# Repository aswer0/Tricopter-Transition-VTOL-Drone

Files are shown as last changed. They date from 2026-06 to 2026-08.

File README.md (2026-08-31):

# Tricopter-Transition-VTOL-Drone

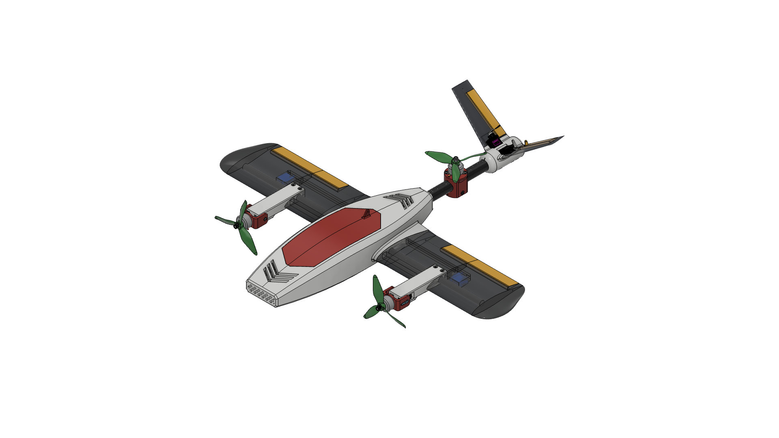
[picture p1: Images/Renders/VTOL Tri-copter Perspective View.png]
Perspective View

This VTOL (Vertical Take-off and Landing) Tricopter UAV (Unmanned Aerial Vehicle) is fully 3D printed and reinforced with carbon fiber rods. It can transition from vertical flight as a standard tricopter to forward flight as a fixed wing UAV by tilting its front 2 propellers.

Demo Link: https://youtube.com/shorts/rxa7jozEfoo?feature=share

***

## Motivation
I was inspired to start this project after seeing the growing usage of standard drones in everyday life. I wanted to combine the efficiency of a fixed wing UAV with the unique ability of a tricopter/quadcopter to hover, which is how I decided on this transition VTOL design.

***

## Specifications
- Length: 650 mm
- Wingspan: 700 mm
- Weight (w/ battery): 870 g
- Max Thrust: 3072 g
- Airfoil: HQ 3.0/14

***

## Bill of Materials (BOM)

| Item | Qty | Cost (USD) | Purchase Link |
| --- | --- | --- | --- |
| 20 × 22 × 330 mm Carbon Fiber Rod | 1 | $12.89 | [Amazon](https://a.co/d/0fRC7tl8) |
| 10 × 12 × 600 mm Carbon Fiber Rod (2 pc) | 1 | $16.99 | [Amazon](https://a.co/d/0hknHJLD) |
| KM1203MD Servo (2 pc pack) | 2 | $56.50 | [Amazon](https://a.co/d/04CT49QQ) |
| 3 mm Bushing | 2 | $6.97 | [Amazon](https://a.co/d/00eb9Lxp) |
| 5 in. Propeller (4 pc pack) | 3 | $9.59 | [Amazon](https://a.co/d/0hknHJLD) |
| RS2205 2300 kV Motor (4 pc pack) | 3 | $36.99 | [Amazon](https://a.co/d/0gNAh0BJ) |
| FS-iA6B Receiver | 1 | $17.99 | [Amazon](https://a.co/d/01dz03wv) |
| AERO SELFIE 4-in-1 45A ESC | 1 | $32.90 | [Amazon](https://a.co/d/0g2pQsMn) |
| MG90S Servo | 4 | $13.88 | [Amazon](https://a.co/d/0epTO13h) |
| Teensy 4.0 | 1 | $24.60 | [Amazon](https://a.co/d/04LAZwGB) |
| MPU6050 9-axis IMU | 1 | $6.99 | [Amazon](https://a.co/d/0g5Ldqw0) |
| Ovonic 4S 1300 mAh LiPo Battery | 1 | $18.99 | [Amazon](https://a.co/d/0c603tkp) |
| 1kg LW-PLA | 1 | $24.99 | [Amazon](https://a.co/d/0acjByZF) |
| 1kg PLA | 1 | $11.99 | [Amazon](https://a.co/d/025aT8S4) |
| M3×6 Button Head Screw | 8 | $9.99 | [Amazon](https://a.co/d/0h7R8a6U) |
| M3×8 Button Head Screw | 6 | | Included in M3 hardware kit |
| M3×14 Button Head Screw | 2 | | Included in M3 hardware kit |
| M3 Nut | 2 | | Included in M3 hardware kit |
| M4×16 Socket Head Screw | 4 | $8.99 | [Amazon](https://a.co/d/0cEMfsPs) |
| M4×30 Button Head Screw | 1 | | Included in M4 hardware kit |
| M4 Nut | 5 | | Included in M4 hardware kit |

Total Cost: $311.24

***

## Printing Instructions

- Every part can be printed on a 180x180x180mm print bed.
- For every wing (W) and aileron (A) part, you need to print one version as is, and one mirrored version.
- These following parts should be printed with vase mode using LW-PLA: W1, W2, W3, A1, A3, F1, C1, C2.
- The "Front Plate" part should be printed out of PLA with 0 top/bottom walls, 2 normal walls and 35% honeycomb infill.
- All other parts should be printed using normal PLA with 2 walls and 2-5% gyroid infill.

***

## Assembly Instructions

Nacelles:
1. Screw a CCW motor onto the front motor mount using 4x M3x6mm screws.
2. Screw the tilt servo (not MG90S) into the right nacelle using the provided self-threading screws.
3. Pressfit a 3mm bushing onto the motor mount.
4. Attach the motor mount to the nacelle by pressfitting a servo horn into the indent, and using a M3x8mm screw to connect the bushing side.
5. Run the wires through the tunnel and out the side.
6. Repeat steps 1-5 for the left side (using a CW motor).

Wing:
1. Glue each wing piece in order using CA glue (W1, W2, W3).
2. Glue each aileron piece together.
3. Run a piece of PLA filament through the aileron hole and use that to attach it to the wing.
4. Use hot glue to attach the MG90S servo.

Fuselage and Canopy:
1. Glue each piece in order using CA glue (F1 in the front, F3 in the back.
2. Glue together the canopy pieces (C1, C2, C3).
3. Using CA glue, attach the front latch piece to the front of C1.
4. Glue the Spring Mount near the seam between C2 and C3.
5. Insert a ballpoint pen spring into the mount, then slide L1 and L2 into the slot in C3 before gluing it in place. The latch should move freely front and back.

Tail:
1. Glue the two tail pieces to the middle clamp.
2. Attach the ruddervators to the tail with a piece of PLA filament as the hinge.
3. Use hot glue to install each MG90S servo.

Assembly:
1. Insert the 600mm CF rod into the side of the fuselage.
2. Slide the wings and nacelles into place and secure with CA glue. Make sure to run the wires using the tunnels into the fuselage.
3. Hot glue the 330mm CF rod into the back of the fuselage.
4. Screw on the back motor to its mount, then clamp the mount onto the CF rod.
5. Slide the tail assembly into place and clamp it using M3 screws. Run the servo wires (with extensions) through the CF tube to the fuselage.

Electronics:
1. Glue the 3 electronics mounts (ESC, Teensy, IMU) into the fuselage.
2. Screw in the ESC using the included M3 screws and rubber grommets.
3. Use VHB to attach the Teensy to its mount, the IMU to its mount, and the receiver to the side of the fuselage.
4. Attach a piece of velcro for the battery somewhere inside F1 so that the position of the battery can be shifted to adjust the center of gravity.
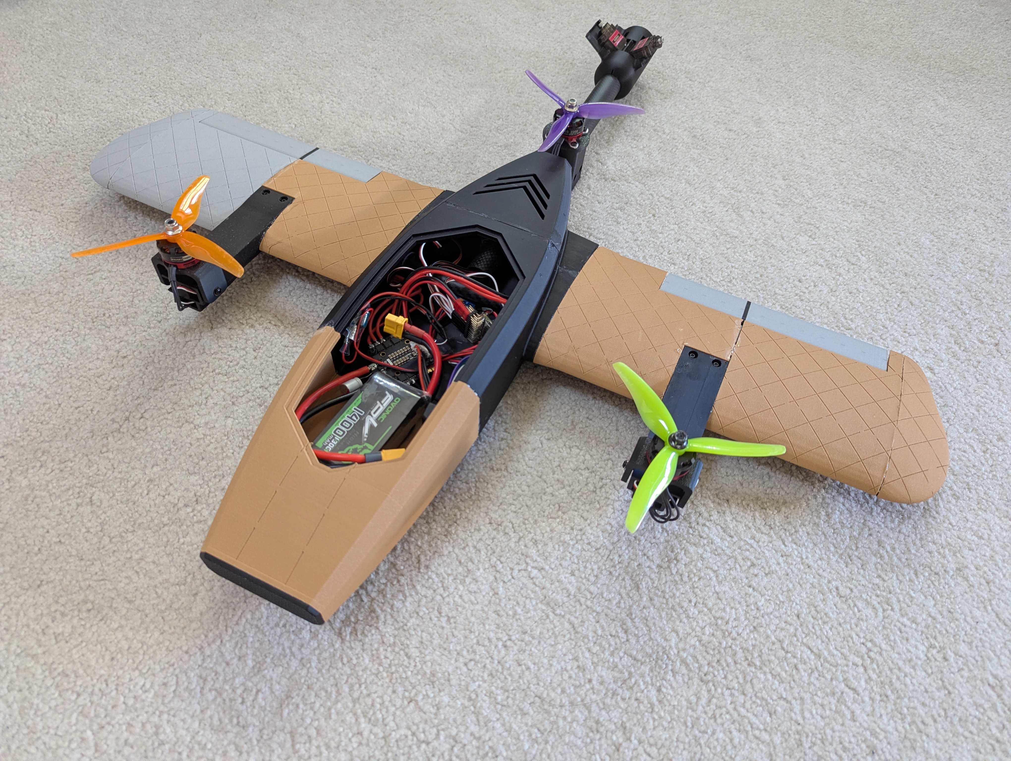
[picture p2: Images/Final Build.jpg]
Build in Progress

***

## Electronics

The electronics are based around the open-sourced flight controller Drehmflight, which uses a Teensy 4.0 board. There are no PCBs involved and all the components are soldered and wired together.

The schematics are shown below, and can also be viewed in KiCAD.


***

## Software

The flight controller runs a modified version of Drehmflight, made by Nicholas Rehm. The full documentation for Drehmflight can be found here: https://github.com/nickrehm/dRehmFlight/blob/master/dRehmFlight%20VTOL%20Documentation.pdf

To compile the firmware, download the source code under the "Firmware" tab, open it in Arduino IDE, then upload to the Teensy 4.0 board over USB.

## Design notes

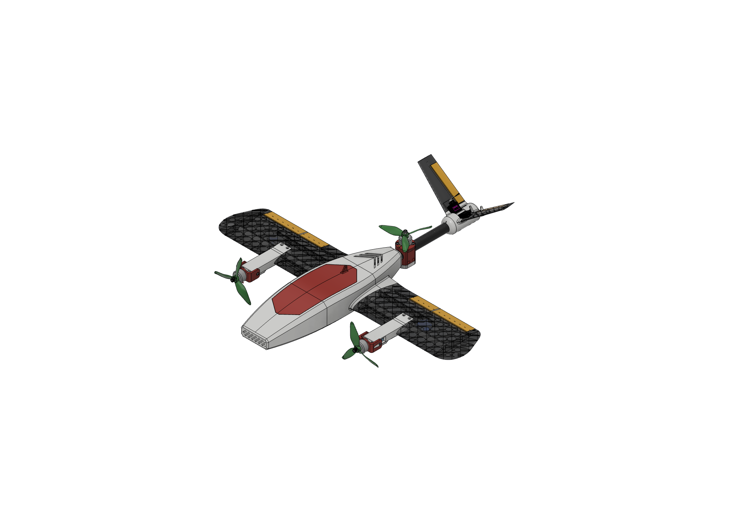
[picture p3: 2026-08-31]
Images/Renders/VTOL Tri-copter v19.png

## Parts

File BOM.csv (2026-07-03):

Item | Qty | Cost (USD) | Purchase Link
20 × 22 × 330 mm Carbon Fiber Rod | 1 | 12.89 | https://a.co/d/0fRC7tl8
10 × 12 × 600 mm Carbon Fiber Rod (2 pc) | 1 | 16.99 | https://a.co/d/0cOCjby6
KM1203MD Servo (2 pc pack) | 2 | 56.50 | https://a.co/d/04CT49QQ
3 mm Bushing | 2 | 6.97 | https://a.co/d/00eb9Lxp
5 in. Propeller (4 pc pack) | 3 | 9.59 | https://a.co/d/07Ut5IjC
RS2205 2300 kV Motor (4 pc pack) | 3 | 36.99 | https://a.co/d/0gNAh0BJ
FS-iA6B Receiver | 1 | 17.99 | https://a.co/d/01dz03wv
AERO SELFIE 4-in-1 45A ESC | 1 | 32.90 | https://a.co/d/0g2pQsMn
MG90S Servo | 4 | 13.88 | https://a.co/d/0epTO13h
Teensy 4.0 | 1 | 24.60 | https://a.co/d/04LAZwGB
MPU6050 9-axis IMU | 1 | 6.99 | https://a.co/d/0g5Ldqw0
Ovonic 4S 1300 mAh LiPo Battery | 1 | 18.99 | https://a.co/d/0c603tkp
1 kg LW-PLA | 1 | 24.99 | https://a.co/d/0acjByZF
1 kg PLA | 1 | 11.99 | https://a.co/d/025aT8S4
M3×6 Button Head Screw | 8 | 9.99 | https://a.co/d/0h7R8a6U
M3×8 Button Head Screw | 6
M3×14 Button Head Screw | 2
M3 Nut | 2
M4×16 Socket Head Screw | 4 | 8.99 | https://a.co/d/0cEMfsPs
M4×30 Button Head Screw | 1
M4 Nut | 5

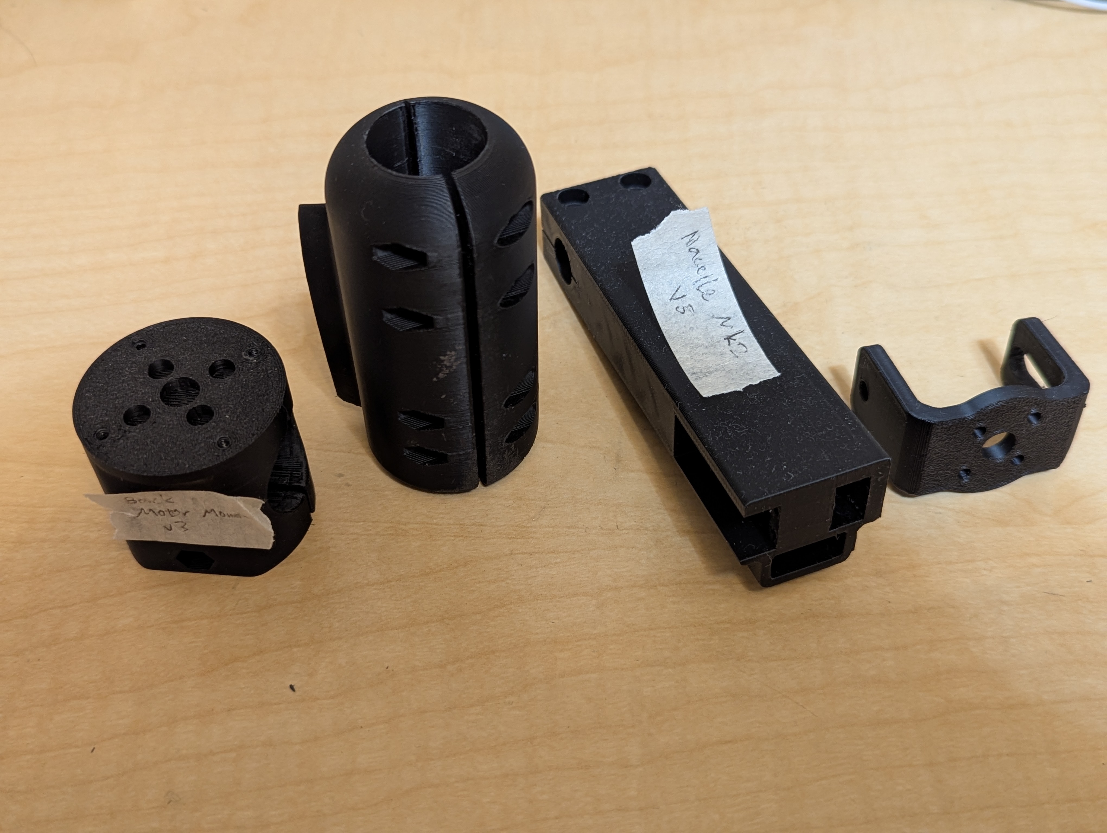
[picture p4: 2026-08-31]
Images/Build/Misc Parts.jpg

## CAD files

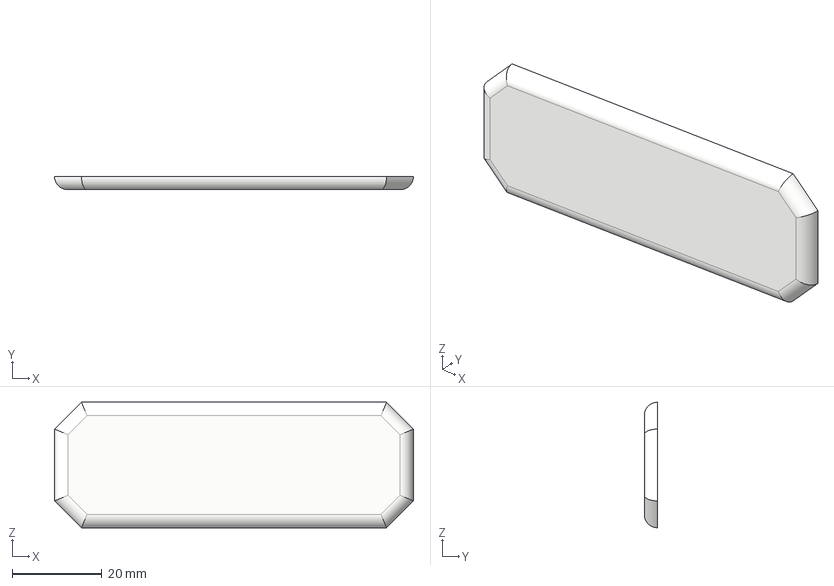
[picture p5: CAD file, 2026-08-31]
CAD/STEP/Fuselage/Front plate.step
80.0 x 3.00 x 28.0 mm

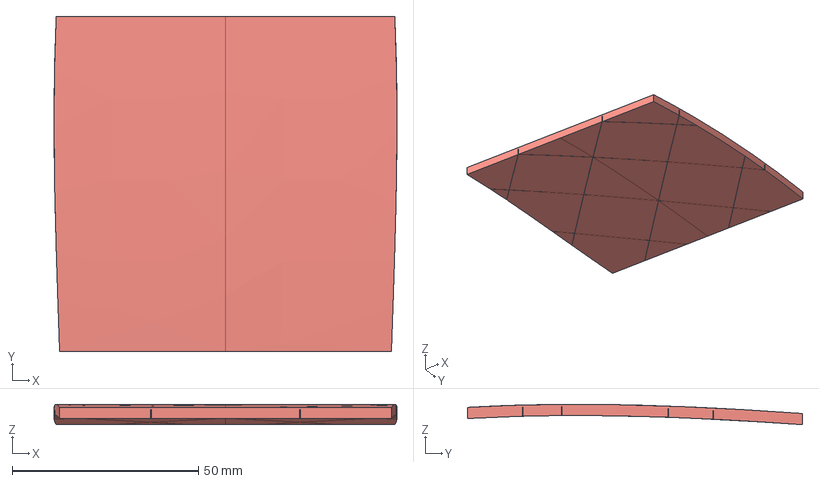
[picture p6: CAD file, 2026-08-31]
CAD/STEP/Miscellaneous/C2.step
92.0 x 90.0 x 5.46 mm

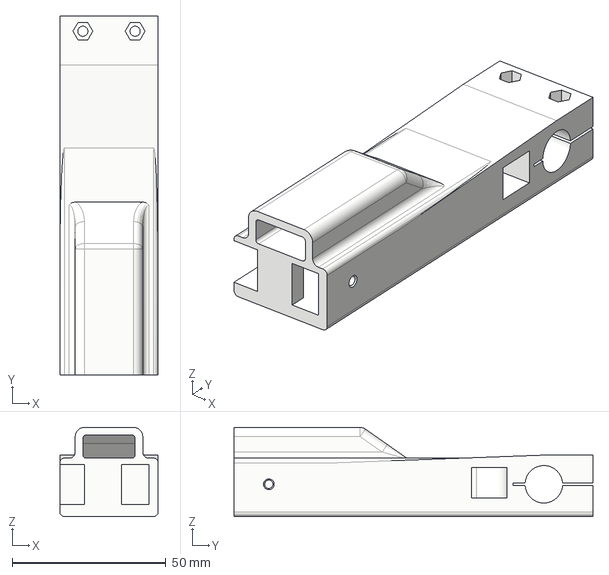
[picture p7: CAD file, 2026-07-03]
CAD/STEP/Nacelles/Nacelle Left.step
32.0 x 116.8 x 29.0 mm

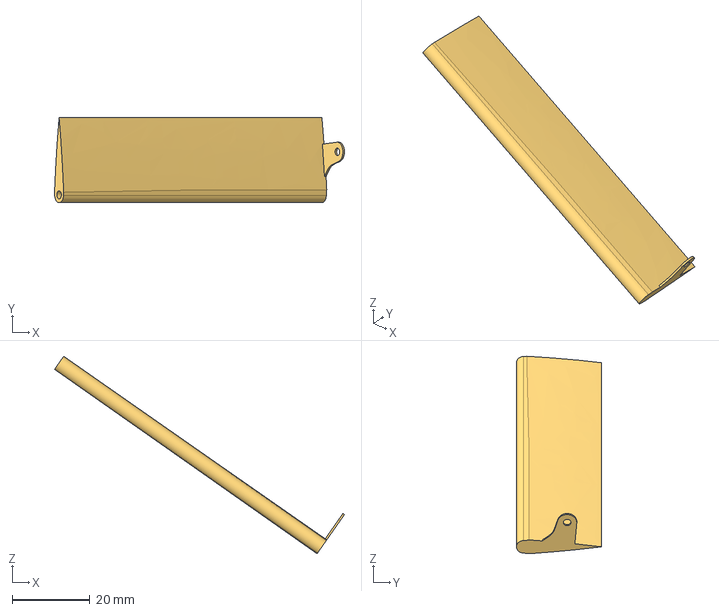
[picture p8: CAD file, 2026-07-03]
CAD/STEP/Tail/Ruddervator2 Right.step
74.8 x 22.0 x 51.0 mm

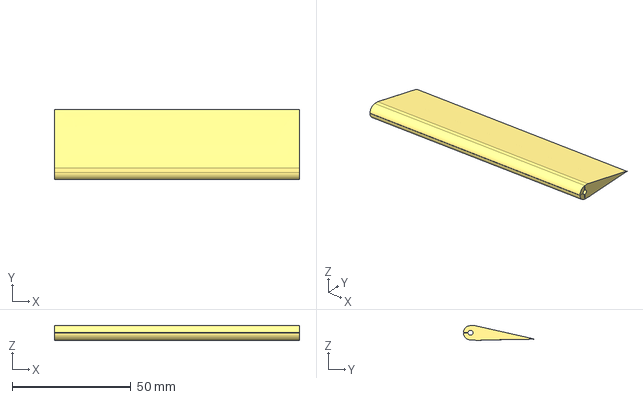
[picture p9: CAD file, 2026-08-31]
CAD/STEP/Wing/A3.step
103.1 x 29.5 x 6.20 mm

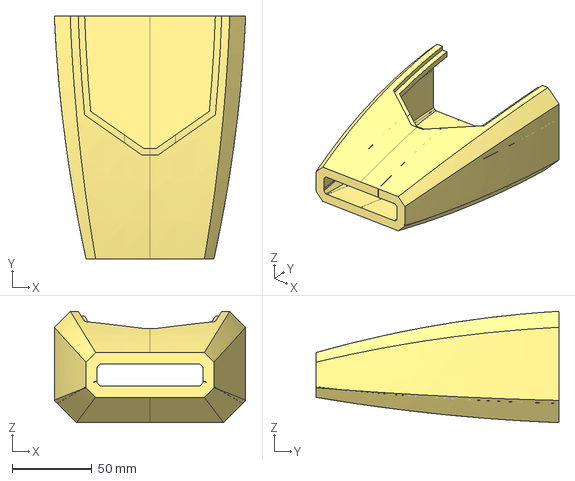
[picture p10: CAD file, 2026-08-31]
CAD/STEP/Fuselage/F1.step
119.7 x 152.0 x 69.7 mm

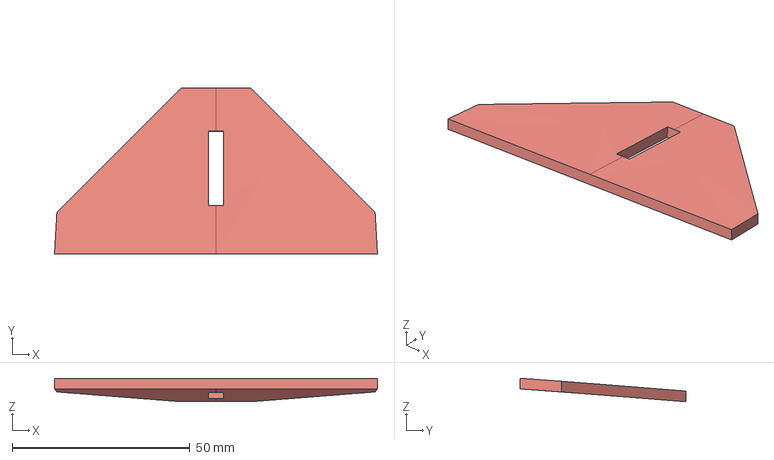
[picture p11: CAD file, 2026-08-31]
CAD/STEP/Miscellaneous/C3.step
90.9 x 46.6 x 6.61 mm

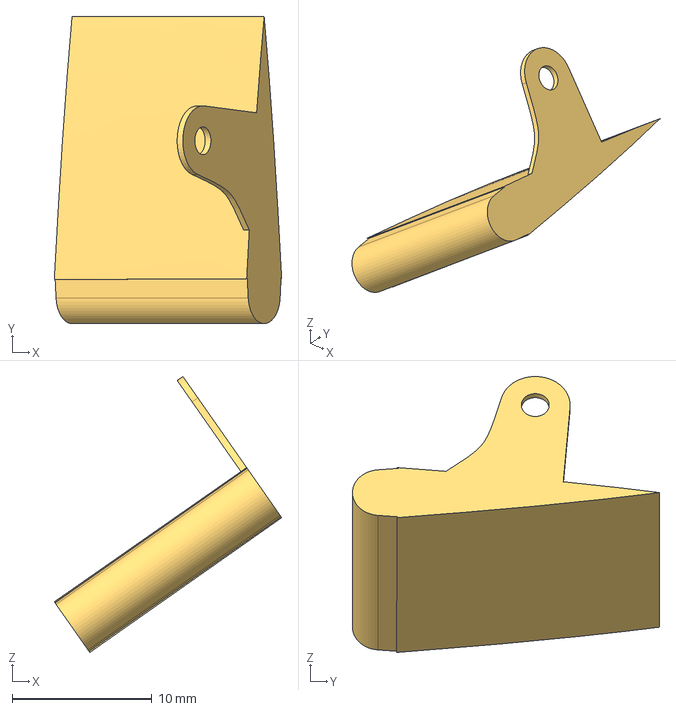
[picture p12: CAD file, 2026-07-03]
CAD/STEP/Tail/Ruddervator1 Left.step
16.3 x 22.0 x 19.8 mm

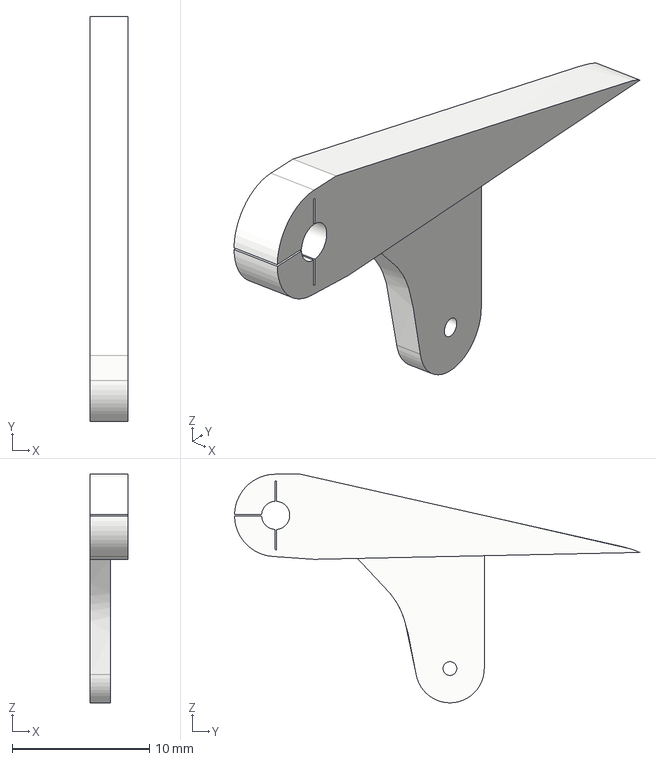
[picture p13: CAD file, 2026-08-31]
CAD/STEP/Wing/A2.step
2.75 x 29.5 x 16.7 mm

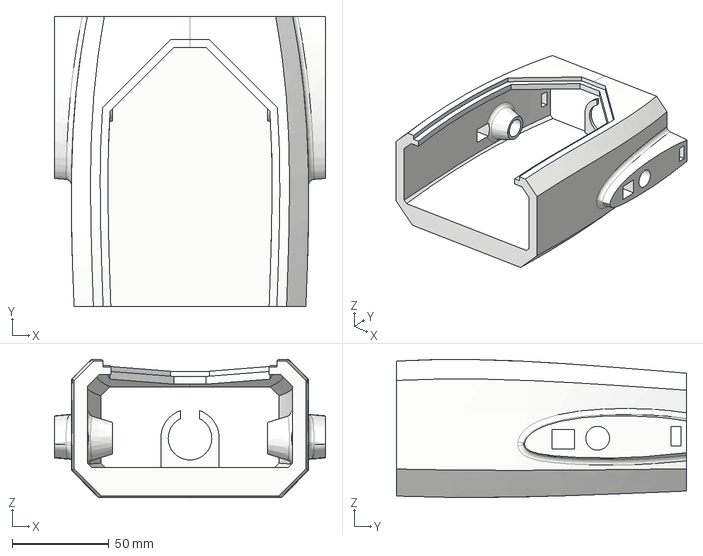
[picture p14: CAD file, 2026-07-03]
CAD/STEP/Fuselage/F2.step
140.0 x 150.0 x 71.3 mm

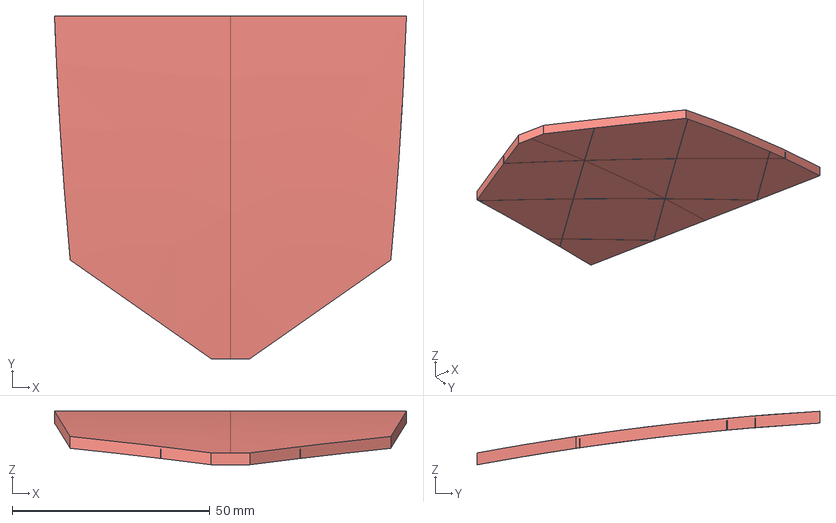
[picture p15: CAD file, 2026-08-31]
CAD/STEP/Miscellaneous/C1.step
89.0 x 86.6 x 13.5 mm

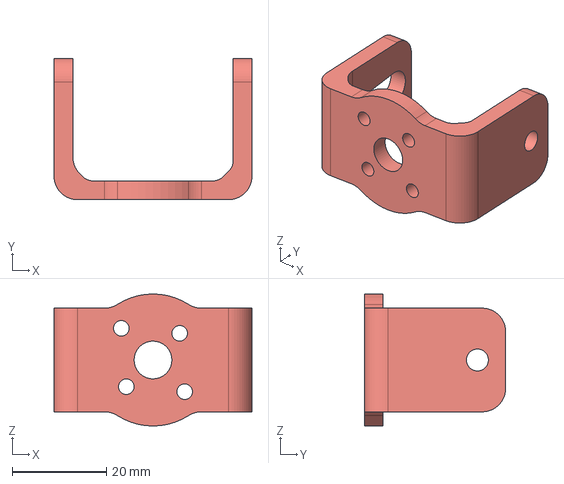
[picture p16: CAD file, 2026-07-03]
CAD/STEP/Nacelles/Front Motor Mount.step
42.0 x 30.0 x 28.0 mm

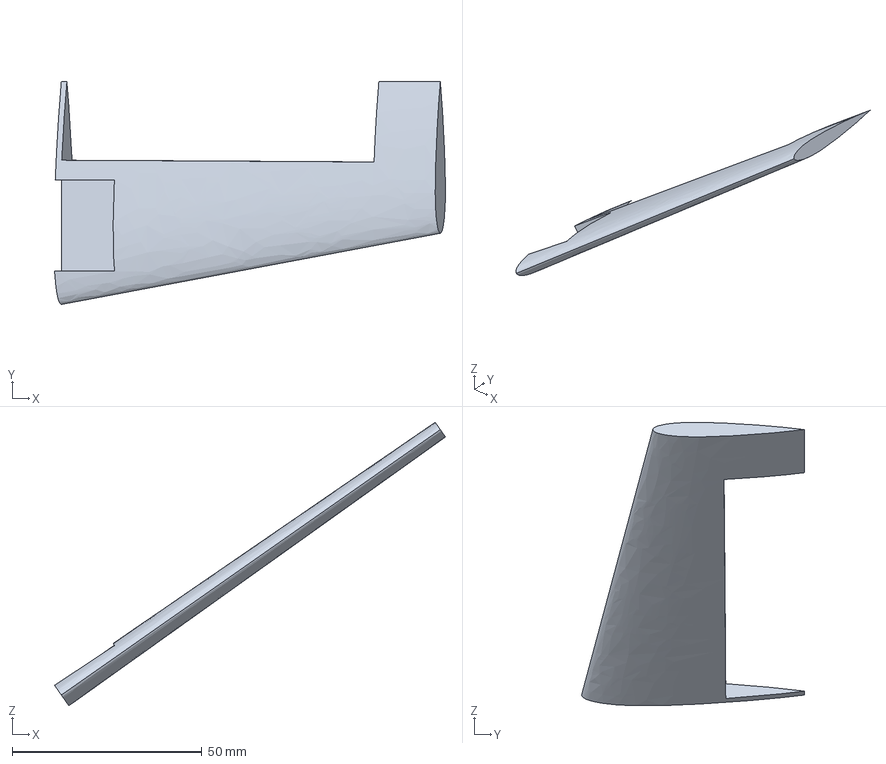
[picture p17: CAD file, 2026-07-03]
CAD/STEP/Tail/Left Tail.step
103.1 x 58.8 x 74.7 mm

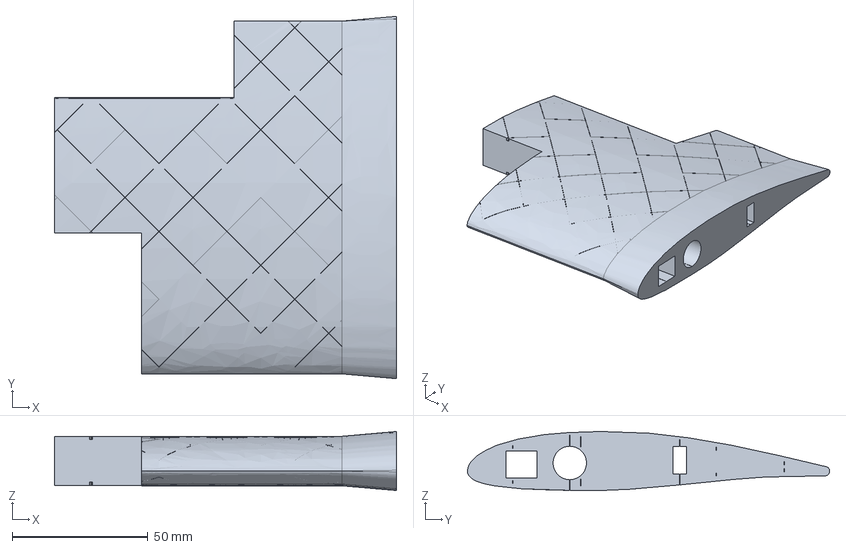
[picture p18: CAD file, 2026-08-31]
CAD/STEP/Wing/W1.step
126.0 x 133.5 x 21.7 mm

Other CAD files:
CAD/STEP/Nacelles/Nacelle Right.step
CAD/STEP/Fuselage/F3.step
CAD/STEP/Miscellaneous/L1.step
CAD/STEP/Tail/Ruddervator1 Right.step
CAD/STEP/Miscellaneous/Back Motor Mount.step
CAD/STEP/Miscellaneous/ESC Mount.step
CAD/STEP/Miscellaneous/Front Latch.step
CAD/STEP/Miscellaneous/IMU Mount.step
CAD/STEP/Miscellaneous/L2.step
CAD/STEP/Miscellaneous/Spring Mount.step
CAD/STEP/Miscellaneous/Teensy_Block Mount.step
CAD/STEP/Tail/Right Tail.step
CAD/STEP/Tail/Ruddervator2 Left.step
CAD/STEP/Tail/Tail Clamp.step
CAD/STEP/Wing/A1.step
CAD/STEP/Wing/W2.step
CAD/STEP/Wing/W3.step
CAD/STL/Fuselage/F1.stl
CAD/STL/Fuselage/F2.stl
CAD/STL/Fuselage/F3.stl
CAD/STL/Fuselage/Front plate.stl
CAD/STL/Miscellaneous/Back Motor Mount.stl
CAD/STL/Miscellaneous/C1.stl
CAD/STL/Miscellaneous/C2.stl
CAD/STL/Miscellaneous/C3.stl
CAD/STL/Miscellaneous/ESC Mount.stl
CAD/STL/Miscellaneous/Front Latch.stl
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

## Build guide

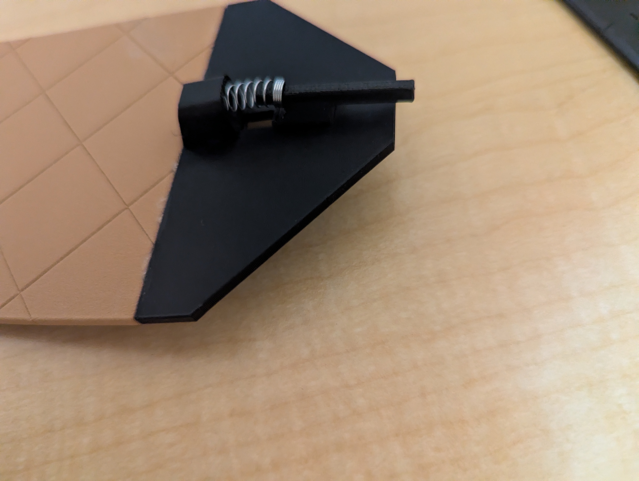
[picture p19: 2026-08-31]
Images/Build/Latch.jpg

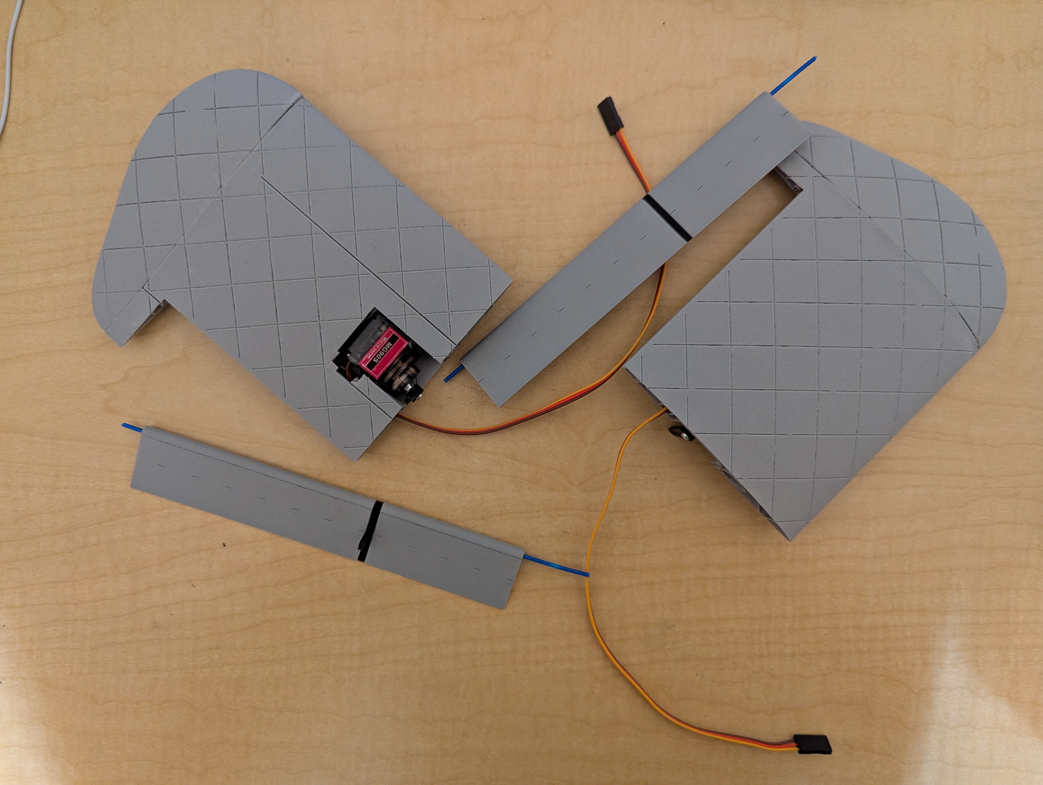
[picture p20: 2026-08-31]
Images/Build/Wings.jpg

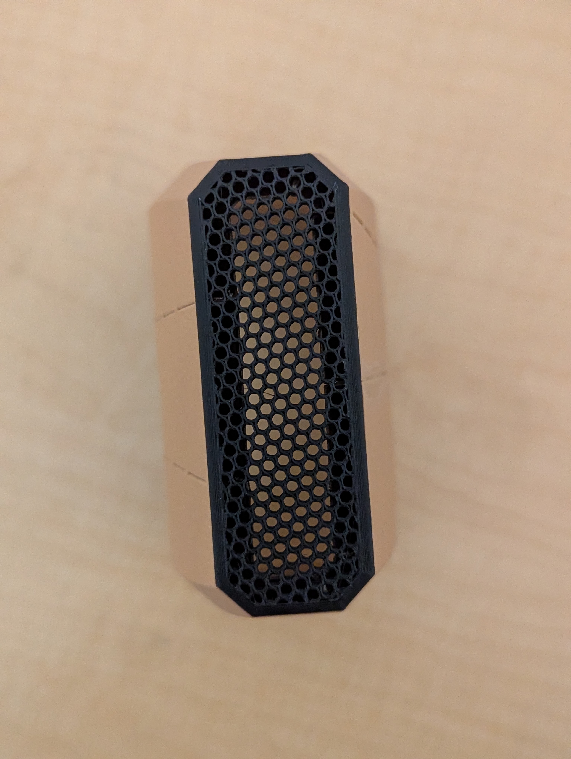
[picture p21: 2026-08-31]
Images/Build/Front plate.jpg

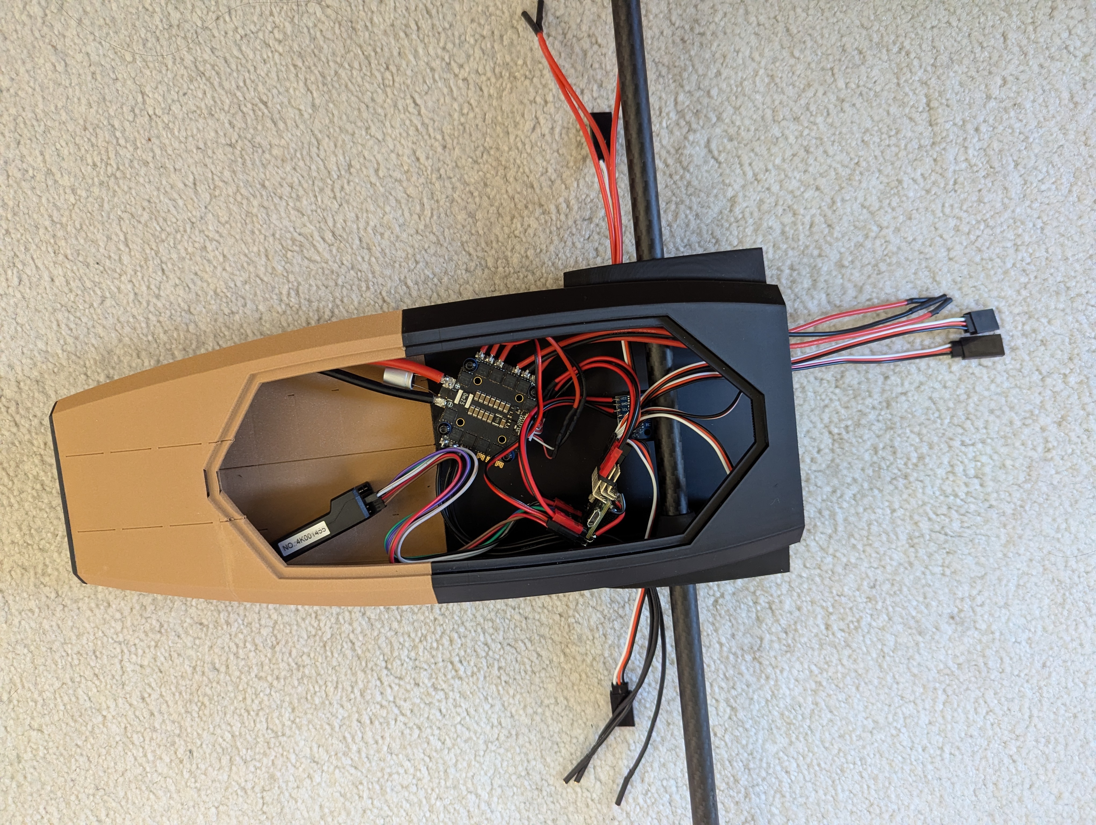
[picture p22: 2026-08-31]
Images/Build/Fuselage Build 1.jpg

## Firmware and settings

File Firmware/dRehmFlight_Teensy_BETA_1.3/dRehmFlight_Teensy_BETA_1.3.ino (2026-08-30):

//Arduino/Teensy Flight Controller - dRehmFlight
//Author: Nicholas Rehm
//Project Start: 1/6/2020
//Last Updated: 7/29/2022
//Version: Beta 1.3
 
//========================================================================================================================//

//CREDITS + SPECIAL THANKS
/*
Some elements inspired by:
http://www.brokking.net/ymfc-32_main.html

Madgwick filter function adapted from:
https://github.com/arduino-libraries/MadgwickAHRS

MPU9250 implementation based on MPU9250 library by:
brian.taylor@bolderflight.com
http://www.bolderflight.com

Thank you to:
RcGroups 'jihlein' - IMU implementation overhaul + SBUS implementation.
Everyone that sends me pictures and videos of your flying creations! -Nick

*/



//========================================================================================================================//
//                                                 USER-SPECIFIED DEFINES                                                 //                                                                 
//========================================================================================================================//

//Uncomment only one receiver type
#define USE_PWM_RX
//#define USE_PPM_RX
//#define USE_SBUS_RX
//#define USE_DSM_RX
static const uint8_t num_DSM_channels = 6; //If using DSM RX, change this to match the number of transmitter channels you have

//Uncomment only one IMU
#define USE_MPU6050_I2C //Default
//#define USE_MPU9250_SPI

//Uncomment only one full scale gyro range (deg/sec)
#define GYRO_250DPS //Default
//#define GYRO_500DPS
//#define GYRO_1000DPS
//#define GYRO_2000DPS

//Uncomment only one full scale accelerometer range (G's)
#define ACCEL_2G //Default
//#define ACCEL_4G
//#define ACCEL_8G
//#define ACCEL_16G



//========================================================================================================================//



//REQUIRED LIBRARIES (included with download in main sketch folder)

#include <Wire.h>     //I2c communication
#include <SPI.h>      //SPI communication
#include <PWMServo.h> //Commanding any extra actuators, installed with teensyduino installer

#if defined USE_SBUS_RX
  #include "src/SBUS/SBUS.h"   //sBus interface
#endif

#if defined USE_DSM_RX
  #include "src/DSMRX/DSMRX.h"  
#endif

#if defined USE_MPU6050_I2C
  #include "src/MPU6050/MPU6050.h"
  MPU6050 mpu6050;
#elif defined USE_MPU9250_SPI
  #include "src/MPU9250/MPU9250.h"
  MPU9250 mpu9250(SPI2,36);
#else
  #error No MPU defined... 
#endif



//========================================================================================================================//



//Setup gyro and accel full scale value selection and scale factor

#if defined USE_MPU6050_I2C
  #define GYRO_FS_SEL_250    MPU6050_GYRO_FS_250
  #define GYRO_FS_SEL_500    MPU6050_GYRO_FS_500
  #define GYRO_FS_SEL_1000   MPU6050_GYRO_FS_1000
  #define GYRO_FS_SEL_2000   MPU6050_GYRO_FS_2000
  #define ACCEL_FS_SEL_2     MPU6050_ACCEL_FS_2
  #define ACCEL_FS_SEL_4     MPU6050_ACCEL_FS_4
  #define ACCEL_FS_SEL_8     MPU6050_ACCEL_FS_8
  #define ACCEL_FS_SEL_16    MPU6050_ACCEL_FS_16
#elif defined USE_MPU9250_SPI
  #define GYRO_FS_SEL_250    mpu9250.GYRO_RANGE_250DPS
  #define GYRO_FS_SEL_500    mpu9250.GYRO_RANGE_500DPS
  #define GYRO_FS_SEL_1000   mpu9250.GYRO_RANGE_1000DPS                                                        
  #define GYRO_FS_SEL_2000   mpu9250.GYRO_RANGE_2000DPS
  #define ACCEL_FS_SEL_2     mpu9250.ACCEL_RANGE_2G
  #define ACCEL_FS_SEL_4     mpu9250.ACCEL_RANGE_4G
  #define ACCEL_FS_SEL_8     mpu9250.ACCEL_RANGE_8G
  #define ACCEL_FS_SEL_16    mpu9250.ACCEL_RANGE_16G
#endif
  
#if defined GYRO_250DPS
  #define GYRO_SCALE GYRO_FS_SEL_250
  #define GYRO_SCALE_FACTOR 131.0
#elif defined GYRO_500DPS
  #define GYRO_SCALE GYRO_FS_SEL_500
  #define GYRO_SCALE_FACTOR 65.5
#elif defined GYRO_1000DPS
  #define GYRO_SCALE GYRO_FS_SEL_1000
  #define GYRO_SCALE_FACTOR 32.8
#elif defined GYRO_2000DPS
  #define GYRO_SCALE GYRO_FS_SEL_2000
  #define GYRO_SCALE_FACTOR 16.4
#endif

#if defined ACCEL_2G
  #define ACCEL_SCALE ACCEL_FS_SEL_2
  #define ACCEL_SCALE_FACTOR 16384.0
#elif defined ACCEL_4G
  #define ACCEL_SCALE ACCEL_FS_SEL_4
  #define ACCEL_SCALE_FACTOR 8192.0
#elif defined ACCEL_8G
  #define ACCEL_SCALE ACCEL_FS_SEL_8
  #define ACCEL_SCALE_FACTOR 4096.0
#elif defined ACCEL_16G
  #define ACCEL_SCALE ACCEL_FS_SEL_16
  #define ACCEL_SCALE_FACTOR 2048.0
#endif



//========================================================================================================================//
//                                               USER-SPECIFIED VARIABLES                                                 //                           
//========================================================================================================================//

//Radio failsafe values for every channel in the event that bad reciever data is detected. Recommended defaults:
unsigned long channel_1_fs = 1000; //thro
unsigned long channel_2_fs = 1500; //ail
unsigned long channel_3_fs = 1500; //elev
unsigned long channel_4_fs = 1500; //rudd
unsigned long channel_5_fs = 2000; //gear, greater than 1500 = throttle cut
unsigned long channel_6_fs = 2000; //aux1

//Filter parameters - Defaults tuned for 2kHz loop rate; Do not touch unless you know what you are doing:
float B_madgwick = 0.04;  //Madgwick filter parameter
float B_accel = 0.14;     //Accelerometer LP filter paramter, (MPU6050 default: 0.14. MPU9250 default: 0.2)
float B_gyro = 0.1;       //Gyro LP filter paramter, (MPU6050 default: 0.1. MPU9250 default: 0.17)
float B_mag = 1.0;        //Magnetometer LP filter parameter

//Magnetometer calibration parameters - if using MPU9250, uncomment calibrateMagnetometer() in void setup() to get these values, else just ignore these
float MagErrorX = 0.0;
float MagErrorY = 0.0; 
float MagErrorZ = 0.0;
float MagScaleX = 1.0;
float MagScaleY = 1.0;
float MagScaleZ = 1.0;

//IMU calibration parameters - calibrate IMU using calculate_IMU_error() in the void setup() to get these values, then comment out calculate_IMU_error()
float AccErrorX = 0.10;
float AccErrorY = 0.02;
float AccErrorZ = -0.08;
float GyroErrorX = -1.26;
float GyroErrorY = -3.09;
float GyroErrorZ = -0.99;

//Controller parameters (take note of defaults before modifying!): 
float i_limit = 25.0;     //Integrator saturation level, mostly for safety (default 25.0)
float maxRoll = 30.0;     //Max roll angle in degrees for angle mode (maximum ~70 degrees), deg/sec for rate mode 
float maxPitch = 30.0;    //Max pitch angle in degrees for angle mode (maximum ~70 degrees), deg/sec for rate mode
float maxYaw = 160.0;     //Max yaw rate in deg/sec

float Kp_roll_angle = 0.1;    //Roll P-gain - angle mode //0.2
float Ki_roll_angle = 0.1;    //Roll I-gain - angle mode 0.3
float Kd_roll_angle = 0.05;   //Roll D-gain - angle mode (has no effect on controlANGLE2)
float B_loop_roll = 0.9;      //Roll damping term for controlANGLE2(), lower is more damping (must be between 0 to 1)
float Kp_pitch_angle = 0.1;   //Pitch P-gain - angle mode //0.2
float Ki_pitch_angle = 0.1;   //Pitch I-gain - angle mode 0.3
float Kd_pitch_angle = 0.05;  //Pitch D-gain - angle mode (has no effect on controlANGLE2)
float B_loop_pitch = 0.9;     //Pitch damping term for controlANGLE2(), lower is more damping (must be between 0 to 1)

float Kp_roll_rate = 0.15;    //Roll P-gain - rate mode
float Ki_roll_rate = 0.2;     //Roll I-gain - rate mode
float Kd_roll_rate = 0.0002;  //Roll D-gain - rate mode (be careful when increasing too high, motors will begin to overheat!)
float Kp_pitch_rate = 0.15;   //Pitch P-gain - rate mode
float Ki_pitch_rate = 0.2;    //Pitch I-gain - rate mode
float Kd_pitch_rate = 0.0002; //Pitch D-gain - rate mode (be careful when increasing too high, motors will begin to overheat!)

float Kp_yaw = 0.35;           //Yaw P-gain
float Ki_yaw = 0.05;          //Yaw I-gain
float Kd_yaw = 0.00015;       //Yaw D-gain (be careful when increasing too high, motors will begin to overheat!)

//constants
const int SERVO1_MIN = 947; //LEFT SERVO
// const int SERVO1_VERTICAL_CENTER = 1050; //raw pwm
// const int SERVO1_HORIZONTAL_CENTER = 2000; //raw pwm
const float SERVO1_VERTICAL_CENTER = 0.12; //0.12
const float SERVO1_HORIZONTAL_CENTER = 0.88;
const int SERVO1_MAX = 2197;

const int SERVO2_MIN = 922; //RIGHT SERVO
// const int SERVO2_VERTICAL_CENTER = 2000; //raw pwm
// const int SERVO2_HORIZONTAL_CENTER = 1050; //raw pwm
const float SERVO2_VERTICAL_CENTER = 0.88; ///0.88
const float SERVO2_HORIZONTAL_CENTER = 0.12;
const int SERVO2_MAX = 2172;

// const float PITCH_TRIM = 0.0;
// const float ROLL_TRIM = 0.0;
// const float PITCH_OFFSET = 14.95; //3.7
// const float ROLL_OFFSET = -1.4; //1.0
const float TORQUE_SCALE = 1;//1.225
const float REAR_HOVER = 1.225; //1.225
const float k_pitch_servo = 1.0;


//========================================================================================================================//
//                                                     DECLARE PINS                                                       //                           
//========================================================================================================================//                                          

//NOTE: Pin 13 is reserved for onboard LED, pins 18 and 19 are reserved for the MPU6050 IMU for default setup
//Radio:
//Note: If using SBUS, connect to pin 21 (RX5), if using DSM, connect to pin 15 (RX3)

//SWAPPED channels around bc stick bind is different on my transmitter
int rawCh1Pin = 15; //throttle
int rawCh2Pin = 16; //ail
int rawCh3Pin = 17; //ele
int rawCh4Pin = 20; //rudd

const int ch1Pin = rawCh3Pin; //throttle
const int ch2Pin = rawCh1Pin; //ail
const int ch3Pin = rawCh2Pin; //ele
const int ch4Pin = rawCh4Pin; //rudd
const int ch5Pin = 21; //gear (throttle cut)
const int ch6Pin = 22; //aux1 (free aux channel)
const int PPM_Pin = 23;
//OneShot125 ESC pin outputs:
const int m1Pin = 0;
const int m2Pin = 1;
const int m3Pin = 2;
const int m4Pin = 3;
const int m5Pin = 4;
const int m6Pin = 5;
//PWM servo or ESC outputs:
const int servo1Pin = 6;
const int servo2Pin = 7;
const int servo3Pin = 8;
const int servo4Pin = 9;
const int servo5Pin = 10;
const int servo6Pin = 11;
const int servo7Pin = 12;
PWMServo servo1;  //Create servo objects to control a servo or ESC with PWM
PWMServo servo2;
PWMServo servo3;
PWMServo servo4;
PWMServo servo5;
PWMServo servo6;
PWMServo servo7;



//========================================================================================================================//



//DECLARE GLOBAL VARIABLES

//General stuff
float dt;
unsigned long current_time, prev_time;
unsigned long print_counter, serial_counter;
unsigned long blink_counter, blink_delay;
bool blinkAlternate;

//Radio communication:
unsigned long channel_1_pwm, channel_2_pwm, channel_3_pwm, channel_4_pwm, channel_5_pwm, channel_6_pwm;
unsigned long channel_1_pwm_prev, channel_2_pwm_prev, channel_3_pwm_prev, channel_4_pwm_prev;

#if defined USE_SBUS_RX
  SBUS sbus(Serial5);
  uint16_t sbusChannels[16];
  bool sbusFailSafe;
  bool sbusLostFrame;
#endif
#if defined USE_DSM_RX
  DSM1024 DSM;
#endif

//IMU:
float AccX, AccY, AccZ;
float AccX_prev, AccY_prev, AccZ_prev;
float GyroX, GyroY, GyroZ;
float GyroX_prev, GyroY_prev, GyroZ_prev;
float MagX, MagY, MagZ;
float MagX_prev, MagY_prev, MagZ_prev;
float roll_IMU, pitch_IMU, yaw_IMU;
float roll_IMU_prev, pitch_IMU_prev;
float q0 = 1.0f; //Initialize quaternion for madgwick filter
float q1 = 0.0f;
float q2 = 0.0f;
float q3 = 0.0f;

//Normalized desired state:
float thro_des, roll_des, pitch_des, yaw_des;
float roll_passthru, pitch_passthru, yaw_passthru;

//Controller:
float error_roll, error_roll_prev, roll_des_prev, integral_roll, integral_roll_il, integral_roll_ol, integral_roll_prev, integral_roll_prev_il, integral_roll_prev_ol, derivative_roll, roll_PID = 0;
float error_pitch, error_pitch_prev, pitch_des_prev, integral_pitch, integral_pitch_il, integral_pitch_ol, integral_pitch_prev, integral_pitch_prev_il, integral_pitch_prev_ol, derivative_pitch, pitch_PID = 0;
float error_yaw, error_yaw_prev, integral_yaw, integral_yaw_prev, derivative_yaw, yaw_PID = 0;

//Mixer
float m1_command_scaled, m2_command_scaled, m3_command_scaled, m4_command_scaled, m5_command_scaled, m6_command_scaled;
int m1_command_PWM, m2_command_PWM, m3_command_PWM, m4_command_PWM, m5_command_PWM, m6_command_PWM;
float s1_command_scaled, s2_command_scaled, s3_command_scaled, s4_command_scaled, s5_command_scaled, s6_command_scaled, s7_command_scaled;
int s1_command_PWM, s2_command_PWM, s3_command_PWM, s4_command_PWM, s5_command_PWM, s6_command_PWM, s7_command_PWM;

//Flight status
bool armedFly = false;

//========================================================================================================================//
//                                                      VOID SETUP                                                        //                           
//========================================================================================================================//
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
   *  Simulates the void loop(), but only for the purpose of providing throttle pass through to the motors, so that you can
   *  power up with throttle at full, let ESCs begin arming sequence, and lower throttle to zero. This function should only be
   *  uncommented when performing an ESC calibration.
   */
   while (true) {
      prev_time = current_time;      
      current_time = micros();      
      dt = (current_time - prev_time)/1000000.0;
    
      digitalWrite(13, HIGH); //LED on to indicate we are not in main loop

      getCommands(); //Pulls current available radio commands
      failSafe(); //Prevent failures in event of bad receiver connection, defaults to failsafe values assigned in setup
      getDesState(); //Convert raw commands to normalized values based on saturated control limits
      getIMUdata(); //Pulls raw gyro, accelerometer, and magnetometer data from IMU and LP filters to remove noise
      Madgwick(GyroX, -GyroY, -GyroZ, -AccX, AccY, AccZ, MagY, -MagX, MagZ, dt); //Updates roll_IMU, pitch_IMU, and yaw_IMU (degrees)
      getDesState(); //Convert raw commands to normalized values based on saturated control limits
      
      m1_command_scaled = thro_des;
      m2_command_scaled = thro_des;
      m3_command_scaled = thro_des;
      m4_command_scaled = thro_des;
      m5_command_scaled = thro_des;
      m6_command_scaled = thro_des;
      s1_command_scaled = thro_des;
      s2_command_scaled = thro_des;
      s3_command_scaled = thro_des;
      s4_command_scaled = thro_des;
      s5_command_scaled = thro_des;
      s6_command_scaled = thro_des;
      s7_command_scaled = thro_des;
      scaleCommands(); //Scales motor commands to 125 to 250 range (oneshot125 protocol) and servo PWM commands to 0 to 180 (for servo library)
    
      throttleCut(); //Directly sets motor commands to low based on state of ch5
      
      servo1.write(s1_command_PWM); 
      servo2.write(s2_command_PWM);
      servo3.write(s3_command_PWM);
      servo4.write(s4_command_PWM);
      servo5.write(s5_command_PWM);
      servo6.write(s6_command_PWM);
      servo7.write(s7_command_PWM);
      commandMotors(); //Sends command pulses to each motor pin using OneShot125 protocol
      
      //printRadioData(); //Radio pwm values (expected: 1000 to 2000)
      
      loopRate(2000); //Do not exceed 2000Hz, all filter parameters tuned to 2000Hz by default
   }
}

float floatFaderLinear(float param, float param_min, float param_max, float fadeTime, int state, int loopFreq){
  //DESCRIPTION: Linearly fades a float type variable between min and max bounds based on desired high or low state and time
  /*  
   *  Takes in a float variable, desired minimum and maximum bounds, fade time, high or low desired state, and the loop frequency 
   *  and linearly interpolates that param variable between the maximum and minimum bounds. This function can be called in controlMixer()
   *  and high/low states can be determined by monitoring the state of an auxillarly radio channel. For example, if channel_6_pwm is being 
   *  monitored to switch between two dynamic configurations (hover and forward flight), this function can be called within the logical 
   *  statements in order to fade controller gains, for example between the two dynamic configurations. The 'state' (1 or 0) can be used
   *  to designate the two final options for that control gain based on the dynamic configuration assignment to the auxillary radio channel.
   *  
   */
  float diffParam = (param_max - param_min)/(fadeTime*loopFreq); //Difference to add or subtract from param for each loop iteration for desired fadeTime

  if (state == 1) { //Maximum param bound desired, increase param by diffParam for each loop iteration
    param = param + diffParam;
  }
  else if (state == 0) { //Minimum param bound desired, decrease param by diffParam for each loop iteration
    param = param - diffParam;
  }

  param = constrain(param, param_min, param_max); //Constrain param within max bounds
  
  return param;
}

float floatFaderLinear2(float param, float param_des, float param_lower, float param_upper, float fadeTime_up, float fadeTime_down, int loopFreq){
  //DESCRIPTION: Linearly fades a float type variable from its current value to the desired value, up or down
  /*  
   *  Takes in a float variable to be modified, desired new position, upper value, lower value, fade time, and the loop frequency 
   *  and linearly fades that param variable up or down to the desired value. This function can be called in controlMixer()
   *  to fade up or down between flight modes monitored by an auxillary radio channel. For example, if channel_6_pwm is being 
   *  monitored to switch between two dynamic configurations (hover and forward flight), this function can be called within the logical 
   *  statements in order to fade controller gains, for example between the two dynamic configurations. 
   *  
   */
  if (param > param_des) { //Need to fade down to get to desired
    float diffParam = (param_upper - param_des)/(fadeTime_down*loopFreq);
    param = param - diffParam;
  }
  else if (param < param_des) { //Need to fade up to get to desired
    float diffParam = (param_des - param_lower)/(fadeTime_up*loopFreq);
    param = param + diffParam;
  }

  param = constrain(param, param_lower, param_upper); //Constrain param within max bounds
  
  return param;
}

void switchRollYaw(int reverseRoll, int reverseYaw) {
  //DESCRIPTION: Switches roll_des and yaw_des variables for tailsitter-type configurations
  /*
   * Takes in two integers (either 1 or -1) corresponding to the desired reversing of the roll axis and yaw axis, respectively.
   * Reversing of the roll or yaw axis may be needed when switching between the two for some dynamic configurations. Inputs of 1, 1 does not 
   * reverse either of them, while -1, 1 will reverse the output corresponding to the new roll axis. 
   * This function may be replaced in the future by a function that switches the IMU data instead (so that angle can also be estimated with the 
   * IMU tilted 90 degrees from default level).
   */
  float switch_holder;

  switch_holder = yaw_des;
  yaw_des = reverseYaw*roll_des;
  roll_des = reverseRoll*switch_holder;
}

void throttleCut() {
  //DESCRIPTION: Directly set actuator outputs to minimum value if triggered
  /*
      Monitors the state of radio command channel_5_pwm and directly sets the mx_command_PWM values to minimum (120 is
      minimum for oneshot125 protocol, 0 is minimum for standard PWM servo library used) if channel 5 is high. This is the last function
      called before commandMotors() is called so that the last thing checked is if the user is giving permission to command
      the motors to anything other than minimum value. Safety first.

      channel_5_pwm is LOW then throttle cut is OFF and throttle value can change. (ThrottleCut is DEACTIVATED)
      channel_5_pwm is HIGH then throttle cut is ON and throttle value = 120 only. (ThrottleCut is ACTIVATED), (drone is DISARMED)
  */
  if ((channel_5_pwm > 1500) || (armedFly == false)) {
    armedFly = false;
    m1_command_PWM = 120;
    m2_command_PWM = 120;
    m3_command_PWM = 120;
    m4_command_PWM = 120;
    m5_command_PWM = 120;
    m6_command_PWM = 120;

    //Uncomment if using servo PWM variables to control motor ESCs
    //s1_command_PWM = 0;
    //s2_command_PWM = 0;
    //s3_command_PWM = 0;
    //s4_command_PWM = 0;
    //s5_command_PWM = 0;
    //s6_command_PWM = 0;
    //s7_command_PWM = 0;
  }
}
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

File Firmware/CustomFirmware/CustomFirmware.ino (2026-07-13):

#include <Servo.h>

int m1_command_PWM, m2_command_PWM, m3_command_PWM;

Servo servo1;
Servo servo2;

const int M1_PIN = 0;
const int M2_PIN = 1;
const int M3_PIN = 2;

const int SERVO1_PIN = 6;
const int SERVO2_PIN = 7;

const int CH1_PIN = 15; //"ch2"
const int CH2_PIN = 16;
const int CH3_PIN = 17;
const int CH4_PIN = 20; //"ch1"
const int CH5_PIN = 21; //blue wire, toggle switch on far left
const int CH6_PIN = 22;

const int RECEIVER_MIN = 1000;
const int RECEIVER_MAX = 2000;

const int SERVO1_MIN = 900;
const int SERVO1_VERTICAL_CENTER = 1050;
const int SERVO1_HORIZONTAL_CENTER = 2000;
const int SERVO1_MAX = 2150;

const int SERVO2_MIN = 900;
const int SERVO2_VERTICAL_CENTER = 2000;
const int SERVO2_HORIZONTAL_CENTER = 1050;
const int SERVO2_MAX = 2150;

unsigned long ch1PWM;
unsigned long ch2PWM;
unsigned long ch3PWM;
unsigned long ch4PWM;
unsigned long ch5PWM;
unsigned long ch6PWM;

unsigned long lastPrint = 0;

void setup()
{
    Serial.begin(115200);
    delay(1000);

    servo1.attach(SERVO1_PIN);
    servo2.attach(SERVO2_PIN);

    servo1.writeMicroseconds(1500);
    servo2.writeMicroseconds(1500);

    motorSetup();
    radioSetup();
}

void loop()
{
    ch1PWM = getRadioPWM(1);
    ch2PWM = getRadioPWM(2);
    ch3PWM = getRadioPWM(3);
    ch4PWM = getRadioPWM(4);
    ch5PWM = getRadioPWM(5);
    ch6PWM = getRadioPWM(6);

    if (ch6PWM > 1700) {
      servo1.writeMicroseconds(SERVO1_VERTICAL_CENTER);
      servo2.writeMicroseconds(SERVO2_VERTICAL_CENTER);
    } else if (ch6PWM < 1300) {
      servo1.writeMicroseconds(SERVO1_HORIZONTAL_CENTER);
      servo2.writeMicroseconds(SERVO2_HORIZONTAL_CENTER);
    }

    scaleCommands();
    commandMotors();

    if (millis() - lastPrint > 100) {
        Serial.print("CH1: ");
        Serial.print(ch1PWM);

        Serial.print(" CH2: ");
        Serial.print(ch2PWM);

        Serial.print(" CH3: ");
        Serial.print(ch3PWM);

        Serial.print(" CH4: ");
        Serial.print(ch4PWM);

        Serial.print(" CH5: ");
        Serial.print(ch5PWM);

        Serial.print(" CH6: ");
        Serial.println(ch6PWM);

        lastPrint = millis();
    }
}

int pwmToOneshot125(int pwm) {
  float scaled = (pwm - 1000) / 1000.0f;
  scaled = constrain(scaled, 0.0f, 1.0f);
  return scaled * 125 + 125;
}

void scaleCommands() {
  //safety switch
  if (ch5PWM > 1500) {
    m1_command_PWM = 125;
    m2_command_PWM = 125;
    m3_command_PWM = 125;
  } else {
    m1_command_PWM = pwmToOneshot125(ch3PWM);
    m2_command_PWM = pwmToOneshot125(ch3PWM);
    m3_command_PWM = pwmToOneshot125(ch3PWM);
  }
}

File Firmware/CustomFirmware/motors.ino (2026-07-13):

void motorSetup() {
    pinMode(M1_PIN, OUTPUT);
    pinMode(M2_PIN, OUTPUT);
    pinMode(M3_PIN, OUTPUT);

    //arm motors
    m1_command_PWM = 200;
    m2_command_PWM = 200;
    m3_command_PWM = 200;
    commandMotors();
    delay(10);
    commandMotors();
    delay(10);

    m1_command_PWM = 125;
    m2_command_PWM = 125;
    m3_command_PWM = 125;
    commandMotors();

}

void commandMotors() {
  int wentLow = 0;
  int pulseStart, timer;

  bool flagM1 = false;
  bool flagM2 = false;
  bool flagM3 = false;

  digitalWrite(M1_PIN, HIGH);
  digitalWrite(M2_PIN, HIGH);
  digitalWrite(M3_PIN, HIGH);

  pulseStart = micros();

  while (wentLow < 3) {
    timer = micros();

    if ((m1_command_PWM <= timer - pulseStart) && !flagM1) {
      digitalWrite(M1_PIN, LOW);
      wentLow += 1;
      flagM1 = true;
    }
    if ((m2_command_PWM <= timer - pulseStart) && !flagM2) {
      digitalWrite(M2_PIN, LOW);
      wentLow += 1;
      flagM2 = true;
    }
    if ((m3_command_PWM <= timer - pulseStart) && !flagM3) {
      digitalWrite(M3_PIN, LOW);
      wentLow += 1;
      flagM3 = true;
    }
  }
}

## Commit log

2026-06-20 Create CAD folder
2026-06-20 upload CAD files
2026-07-03 Added STEP and STL files for individual parts
    [A1 Left.step, A1 Left.stl, A1 Right.step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]
2026-07-03 Update BOM in README.md
2026-07-03 Update assembly instructions in README.md
2026-07-13 Initial firmware commit
    - working servo test
    - working PWM receiver
2026-07-13 working motor firmware
2026-07-24 added schematics
    [Tricopter VTOL.kicad_pcb, Tricopter VTOL.kicad_sch]
2026-07-24 Update README.md
    added schematics in electronics section
2026-08-31 update CAD models
    [A1 Left.step, A1 Left.stl, A1 Right.step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]
2026-08-31 Update README.md
    Updated software, printing, and assembly instructions
